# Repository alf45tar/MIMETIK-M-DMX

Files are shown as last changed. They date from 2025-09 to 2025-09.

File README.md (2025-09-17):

# DMX Smoke Machine Controller

DMX512 controller add-on for the **SDJ / Sagitter / Proel** [**MIMETIK-M**](https://www.sdjlighting.com/en/prodotto/sg-mimetikm-smoke-machine-mimetik-900w/)  smoke machine.
Provides pulse-based DMX smoke control with ready-state detection and a neat 3D-printed enclosure.  

## 💡 Compatibility
- ✅ Tested with **SDJ Mimetik-M**  
- ⚠️ May also work with machines sharing the **same timer/remote port pinout**  
- ❌ Not universal — always check wiring before use  

## ✨ Features
- DMX512 input via RS485 transceiver  
- READY/WARM-UP detection (machine won’t fire until warmed up)  
- Pulse control: DMX value maps to **pulse duration** and **pulse period**  
- Feedback PWM LED (DMX level, pin 9)  
- Smoke pulse LED (mirrors smoke firing, pin 10)  
- READY LED (built-in pin 13)  
- Compact 3D-printed enclosure that mounts directly using factory screws  

## 🛠 Bill of Materials
| Item | Quantity | Notes |
|---|---|---|
| Arduino Uno R3 | 1 | Reference/tested board (⚠️ must be powered separately — not from timer port) |
| Protoshield v.5 | 1 | For soldering & integration |
| MAX485 **or** SN75176 module | 1 | RS485 transceiver |
| PN2222 transistor | 1 | Smoke trigger driver |
| LEDs + resistors | optional | Status & feedback indicators |

## 📌 Timer Port Pinout
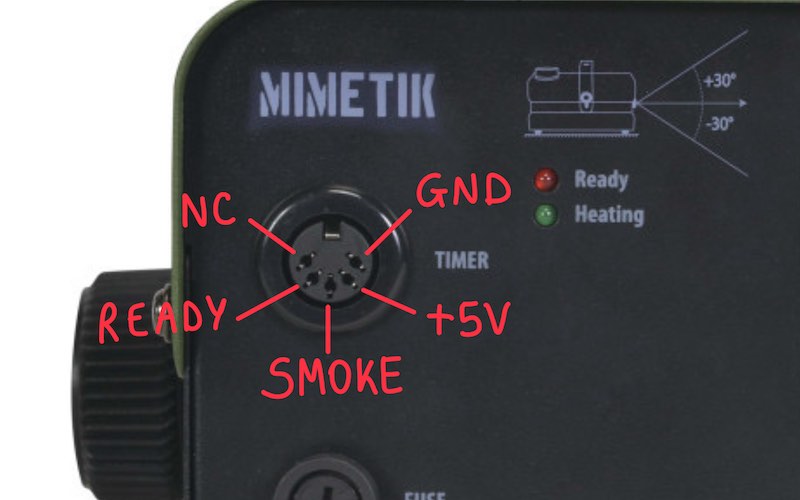
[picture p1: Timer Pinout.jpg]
Pinout


| Label | Direction | Description |
|---|---|---|
| GND | Common | Ground reference |
| +5V | Output | **Low-current reference only** — cannot power Arduino |
| SMOKE | Input | Active LOW → pulling to GND triggers smoke |
| READY | Output | HIGH when warmed up, LOW during warm-up |
| NC | – | Not connected |

⚠️ **Important:** The +5 V pin from the timer/remote port is **not able to supply enough current to run an Arduino**.  
Use a separate Arduino power source (USB, barrel jack, VIN, or stable +5 V).

---

## 🔌 Arduino Connections
| Arduino Pin | Function | Notes |
|---|---|---|
| `2`  | Direction pin | Required by **LXUSARTDMX** |
| `8`  | `smokePin` | Smoke trigger |
| `9`  | `feedbackPin` | PWM output showing DMX level |
| `10` | `smokeLedPin` | LED mirrors smoke pulses |
| `12` | `readyPin` | Input from machine READY |
| `13` | `ledPin` | Built-in LED mirrors READY |

# Schematic

## DMX connector wiring
```
Arduino                                               DMX connector

    +5V  --------------------------------------+
                                               |                                 
                          +---------------+    |
     RX  -----------------| R         VCC |----+
                          |               |
                     +----| RE/         B |----------  Data - (XLR pin 2)
                     |    |    SN75176    |
      2  ------------+----| DE          A |----------  Data + (XLR pin 3)
                          |               |
     TX  -----------------| D         GND |---+------  Ground (XLR pin 1)
                          +---------------+   |
                                              |
    GND  -------------------------------------+                                       
```

## Timer port wiring
```
Arduino                                      Timer Port

                           +---------------  SMOKE
                           |
                           |
                           |  
                         | /  C
             470-680 Ω   |/     
      8  -----\/\/\/\----|    PN22222
                       B |\
                         | v  E
                           |
                           |
                           |
    GND  ------------------+---------------  GND                    

     12  ----------------------------------  READY

```

## Led wiring (optional)
```
Arduino
               220Ω
      9  -----\/\/\/\-----|>|-----+  DMX feedback LED
                                  |
               220Ω               |
     10  -----\/\/\/\-----|>|-----+  Smoke pulse LED
                                  |
                                  |
    GND  -------------------------+            
```

## 🔋 Powering the Arduino

The smoke machine’s **timer port +5 V cannot power the Arduino** (insufficient current).  
Use one of the standard Arduino Uno power options instead:

| Method | Pin/Port | Notes |
|---|---|---|
| **USB** | USB-B port | Easiest option, 5 V regulated by PC/adapter |
| **Barrel jack (VIN)** | 2.1 mm center-positive | Accepts 7–12 V (recommended 9 V); onboard regulator steps it down |
| **VIN pin** | Header pin labeled `VIN` | Same as barrel jack, feed 7–12 V into this pin |
| **+5 V pin** | Header pin labeled `5V` | Direct regulated 5 V input (⚠️ bypasses onboard regulator, only safe if supply is stable) |

⚠️ Never connect power simultaneously to multiple inputs (e.g. USB and VIN) unless you know exactly how Arduino’s auto-select circuitry works.  

## ⚙️ Software Behavior
- **DMX channel:** `503` (change in code if desired)
- **READY = LOW** → warm-up → smoke disabled  
- **DMX mapping**  
  - `0` = smoke OFF  
  - `1` = short pulse (**0.1 s ON / 9.9 s OFF**)  
  - `255` = continuous smoke (**1 s ON every 1 s cycle → always ON**)  
  - Intermediate DMX values scale linearly between these extremes  
- **Pulse cycle**  
  - For each cycle:  
    - Smoke ON for mapped duration  
    - Smoke OFF until the mapped period completes  
  - At DMX 255, duration = period → machine runs continuously  
  - Responds instantly to DMX changes mid-cycle  
- **LED indicators**  
  - Pin 9: PWM LED shows DMX level  
  - Pin 10: LED mirrors smoke pulse (ON when machine is triggered)  
  - Pin 13: Built-in LED follows READY state  
- **Failsafe**
  - Smoke is forced OFF if:
      - Machine is warming up (READY LOW)
      - DMX signal is lost for >3s
      - DMX=0
      
## 📊 DMX Pulse Example
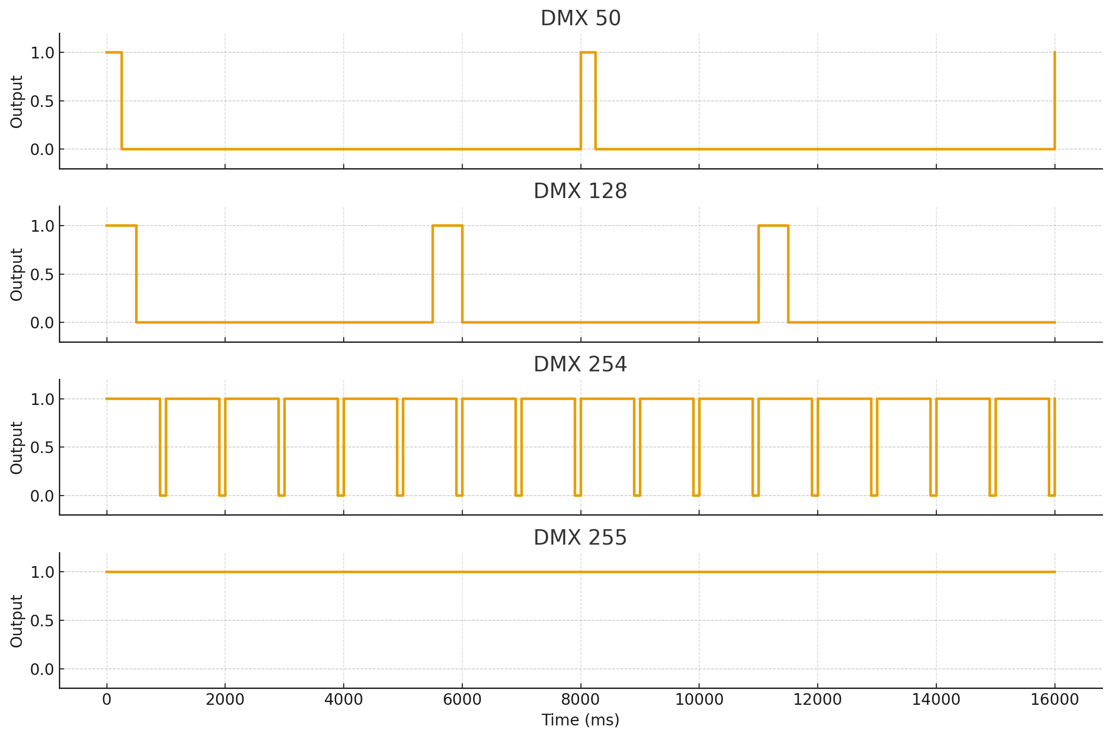
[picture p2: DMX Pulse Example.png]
Pulse Example


## ▶️ Usage
1. Print the enclosure and assemble the electronics.  
2. Mount to left or right side of the machine with existing screws.  
3. Connect to the **timer/remote port**.  
4. **Power the Arduino** via USB, barrel jack/VIN, or +5 V pin from a regulated supply.  
   ⚠️ Do **not** use the timer port’s +5 V — it cannot supply enough current.  
5. Upload the Arduino sketch (tested on Uno R3).  
6. Send DMX values to the configured channel.  

## 🔧 PN2222 Transistor Notes

The **PN2222** is a common NPN bipolar junction transistor (BJT) used as a **switch** in the DMX smoke machine controller.

### Purpose

The Arduino’s digital output pin cannot directly drive the smoke machine’s timer input (which typically activates a coil inside the machine, like a relay) because the relay expects **higher current than the Arduino pin can safely supply**. The PN2222 acts as a **current amplifier** to safely trigger the smoke machine.

### How it Works

1. Arduino outputs a small current to the transistor **base** through a resistor (560 Ω in the schematic).
2. This turns the transistor **ON**, allowing current to flow from **collector to emitter**, which pulls the smoke trigger line LOW.
3. When the Arduino pin is LOW, the transistor switches OFF, and the smoke line returns to HIGH (inactive).

### Base Resistor Note

* The 560 Ω resistor sets the current into the transistor’s base.
* It can be replaced with a **470 Ω** or **680 Ω** resistor depending on available components.

### Benefits

* Protects the Arduino from excessive current draw.
* Provides fast switching for precise smoke pulses.
* Compatible with standard 5 V logic levels.
* Cheap, widely available, and reliable.

## Photos

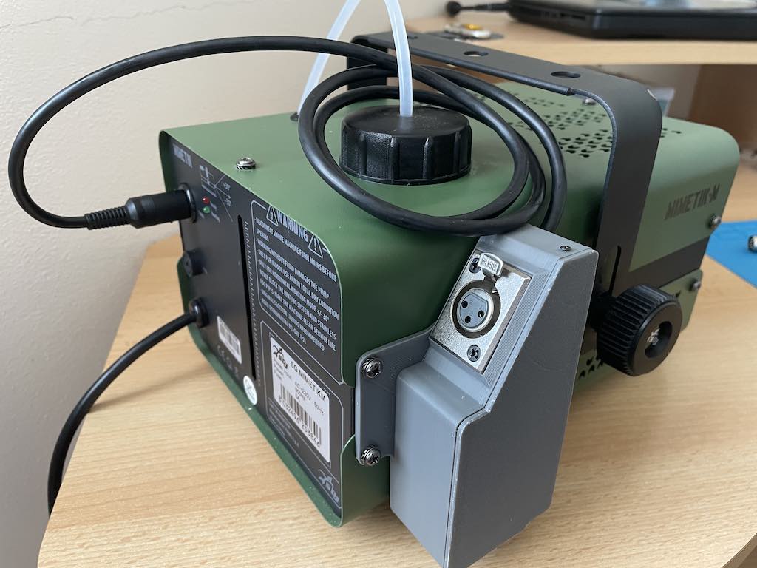
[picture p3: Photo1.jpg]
Outside

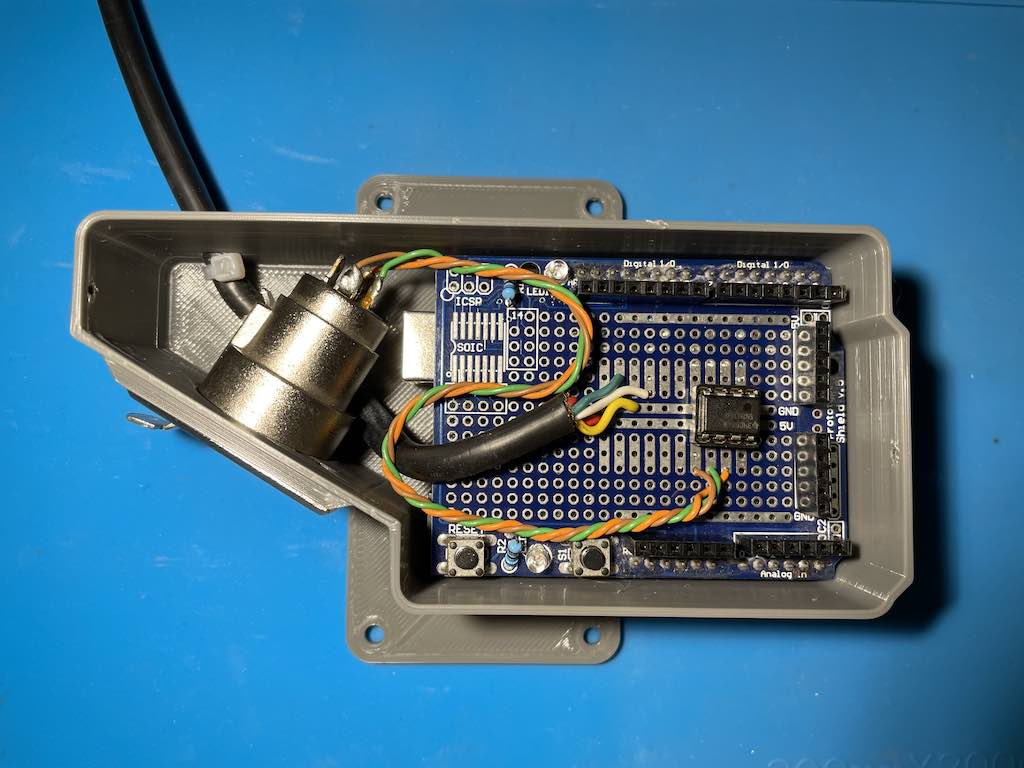
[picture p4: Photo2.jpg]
Inside


## ⚠️ Safety Notes
- Smoke machines run on **mains voltage** — isolate low-voltage electronics.  
- Double-check wiring before powering on.  
- Only use with machines confirmed to share the SDJ Mimetik-M pinout.  
- ⚠️ The **+5 V timer port output cannot power the Arduino** (insufficient current).  
  Use USB or the barrel jack with an external supply.  

## 📜 License
MIT License – free to use, adapt, and improve.

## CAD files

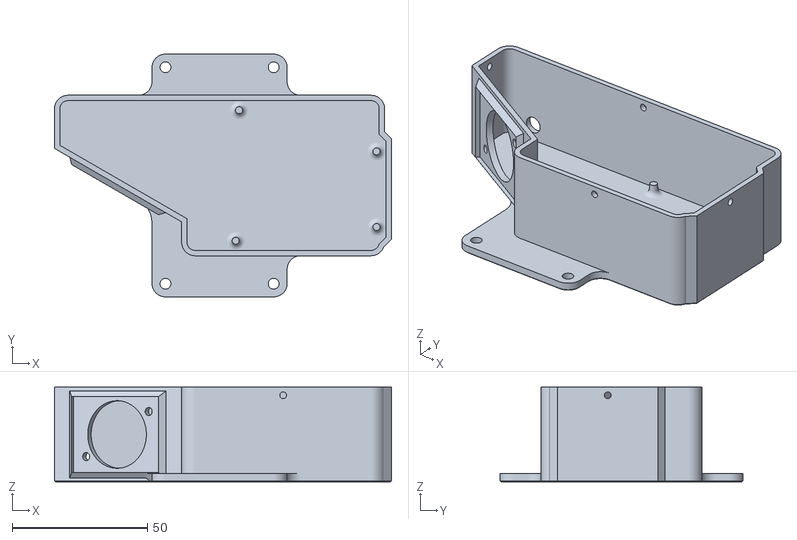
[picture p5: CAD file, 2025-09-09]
Box.stl
124.6 x 89.7 x 35.0

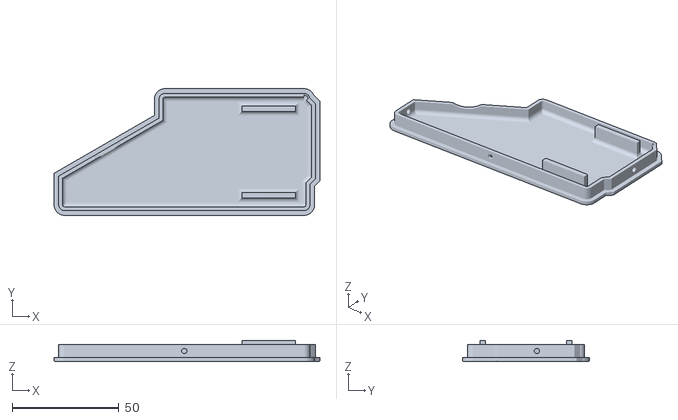
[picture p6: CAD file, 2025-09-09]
Cover.stl
124.6 x 59.3 x 10.0

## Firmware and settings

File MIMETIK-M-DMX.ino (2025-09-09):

/*
===============================================================================
  SMOKE CONTROLLER (Arduino + DMX)
===============================================================================

LEDs:
- Pin 13 → READY indicator (follows smoke machine warm-up/ready signal)
- Pin 10 → Smoke activity LED (follows actual smoke ON/OFF pulses)
- Pin 9  → Received DMX value is the PWM duty cycle

-------------------------------------------------------------------------------
STATE MACHINE
-------------------------------------------------------------------------------
States:
  IDLE     → OFF, waiting for next pulse
  PULSING  → ON, active for pulseDuration
  WAITING  → OFF, gap until next pulse
  FULL_ON  → ON, continuous (DMX=255)

-------------------------------------------------------------------------------
TIMING BEHAVIOR (examples)
-------------------------------------------------------------------------------

DMX = 0   → OFF, no pulses (IDLE)
DMX = 50  → pulseDuration ~250 ms, period ~8000 ms
             [ON--250ms][OFF-----------------7750ms-----------------][ON...]

DMX = 128 → pulseDuration ~500 ms, period ~5500 ms
             [ON--500ms][OFF----------------5000ms----------------][ON...]

DMX = 254 → pulseDuration ~900 ms, period ~1000 ms
             [ON--900ms][OFF-100ms][ON--900ms][OFF-100ms]...

DMX = 255 → FULL_ON (continuous ON, no pulses)
             [ON--------------------------------------------------------------]

-------------------------------------------------------------------------------
FAILSAFE
-------------------------------------------------------------------------------
- If smoke machine is warming up (READY=LOW) → forced OFF
- If DMX signal lost for >3s → forced OFF
- DMX=0 → forced OFF
===============================================================================
*/

#include <Arduino.h>
#include <LXUSARTDMX.h>

// --- Config ---
const int dmxChannel  = 503;  // DMX channel
const int readyPin    = 12;   // READY input from smoke machine
const int ledPin      = 13;   // onboard LED = READY indicator
const int smokePin    = 8;    // smoke control (tri-state)
const int pulseLedPin = 10;   // LED follows smoke ON/OFF
const int feedbackPin = 9;    // feedback PWM

// --- Timing ---
uint16_t pulseDuration = 200;   // ms
uint16_t period        = 5000;  // ms

unsigned long pulseStartTime = 0;
unsigned long nextPulseTime  = 0;
unsigned long lastDMXMillis  = 0;
const unsigned long dmxTimeout = 3000; // ms

// --- State ---
enum SmokeState { IDLE, PULSING, WAITING, FULL_ON };
SmokeState state = IDLE;

byte lastDMXValue = 0;
bool prevReadyState = false;

// --- Helpers ---
void smokeOn() {
  digitalWrite(smokePin, HIGH);
  digitalWrite(pulseLedPin, HIGH); // LED follows smoke ON
  pulseStartTime = millis();
  state = PULSING;
}

void smokeFullOn() {
  digitalWrite(smokePin, HIGH);    // permanently ON
  digitalWrite(pulseLedPin, HIGH); // LED ON solid
  state = FULL_ON;
}

void smokeOff() {
  digitalWrite(smokePin, LOW);
  digitalWrite(pulseLedPin, LOW);  // LED follows smoke OFF
  state = IDLE;
}

// --- DMX callback ---
void gotDMXCallback(int slots) {
  lastDMXMillis = millis(); // refresh "alive" watchdog
}

// --- Update smoke logic ---
void updateSmoke() {
    unsigned long now = millis();
    bool readyState = digitalRead(readyPin);

    // READY indicator LED mirrors machine status
    digitalWrite(ledPin, readyState);

    // --- Warm-up / Ready detection ---
    if (readyState != prevReadyState) {
        prevReadyState = readyState;
        if (readyState) {
            nextPulseTime = now;  // can start immediately
        } else {
            smokeOff();
        }
    }

    if (!readyState) {
        smokeOff();
        return;
    }

    // --- DMX input ---
    byte dmxValue = LXSerialDMX.getSlot(dmxChannel);

    // --- DMX failsafe ---
    if (millis() - lastDMXMillis > dmxTimeout) {
        analogWrite(feedbackPin, 0); // force LOW = DMX lost
        smokeOff();
        return;
    } else {
        analogWrite(feedbackPin, dmxValue); // show live DMX value
    }

    // --- IDLE handling ---
    if (dmxValue == 0) {
        smokeOff();
        return;
    }

    // --- FULL_ON handling ---
    if (dmxValue == 255) {
        if (state != FULL_ON) {
            smokeFullOn();
        }
        return; // skip pulsing logic
    } 
    else if (state == FULL_ON) {
        // Exit FULL_ON when DMX < 255
        smokeOff(); 
    }

    // --- Calculate pulseDuration and period for 1–254 DMX ---
    uint16_t newPulseDuration = map(dmxValue, 1, 254, 100, 900);
    uint16_t newPeriod = map(dmxValue, 1, 254, 10000, 1000);

    // --- Adjust timings mid-pulse to avoid glitches ---
    if (state == PULSING) {
        unsigned long elapsed = now - pulseStartTime;
        if (elapsed >= newPulseDuration) {
            smokeOff();
            nextPulseTime = now + (newPeriod - newPulseDuration);
            state = WAITING;
        } else {
            pulseDuration = newPulseDuration;
            period = newPeriod;
        }
    } 
    else if (state == WAITING) {
        unsigned long remaining = (nextPulseTime > now) ? nextPulseTime - now : 0;
        if (remaining > newPeriod - newPulseDuration) {
            nextPulseTime = now + (newPeriod - newPulseDuration);
        }
        pulseDuration = newPulseDuration;
        period = newPeriod;

        if (now >= nextPulseTime) {
            smokeOn();
        }
    } 
    else if (state == IDLE) {
        pulseDuration = newPulseDuration;
        period = newPeriod;
        if (now >= nextPulseTime) {
            smokeOn();
        }
    }
}

// --- Setup ---
void setup() {
    pinMode(readyPin, INPUT);
    pinMode(ledPin, OUTPUT);  
    pinMode(pulseLedPin, OUTPUT);
    pinMode(feedbackPin, OUTPUT);
    pinMode(smokePin, OUTPUT);
    smokeOff();

    LXSerialDMX.setDirectionPin(2);
    LXSerialDMX.setDataReceivedCallback(&gotDMXCallback);
    LXSerialDMX.startInput();
    lastDMXMillis = millis();
}

// --- Main loop ---
void loop() {
    updateSmoke();
}

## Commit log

2025-09-09 Revise pinout section in README
    Updated pinout section to include timer port pinout and removed unnecessary details.
2025-09-09 Update LED wiring section to optional
2025-09-09 Label LEDs in wiring diagram
    Added labels for DMX feedback LED and Smoke pulse LED.
2025-09-09 Add PN2222 transistor usage notes to README
    Added detailed notes on using the PN2222 transistor as a switch in the DMX smoke machine controller, including its purpose, operation, base resistor options, and benefits.
2025-09-09 Update README to clarify PN2222 function
    Clarified the role of the PN2222 in triggering the smoke machine by specifying that it activates a coil, like a relay.
2025-09-17 Revise wiring diagrams for Timer and LED
    Updated wiring diagrams for Timer and LED connections in README.
